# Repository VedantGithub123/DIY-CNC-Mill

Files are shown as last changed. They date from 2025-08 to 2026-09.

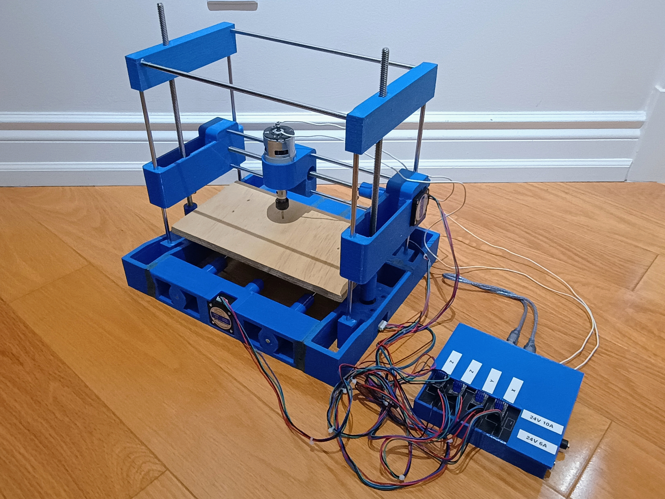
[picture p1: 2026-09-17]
media/build.jpg

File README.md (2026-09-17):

# Project Overview

The goal of this project is to develop a G-code interpreter and CNC mill. The CNC mill can follow straight lines, arcs and cubic bezier curves. It is 3D-printed with PETG, uses stepper motors, which are controlled with an Arduino Mega. The code ran on the laptop sends motor speeds to the Arduino, which moves the motors accordingly. To use the program, connect the Arudino Mega to your laptop with a USB cable. Run the Python file 

## Getting Started

SolidWorks is used for the CAD

KiCAD is used for the circuit diagram and PCB

Ensure Git is installed and setup to work with he repository

Clone the project repository to your local machine and navigate into the directory:
```
git clone https://github.com/VedantGithub123/DIY-CNC-Mill
cd DIY-CNC-Mill
```

Python and the PyGame library are needed

Arduino and the AccelStepper library are needed

## Repository Structure

The `main` branch is the organized working branch. Below is an overview of the folder structure for the `main` branch of this repository
```
DIY-CNC-Mill/
├── build/
├── electrical/
├── input/
├── media/
├── src/
│   ├── arduino/
│   ├── assets/
│   └── run.py
└── README.md
```

### Folder Descriptions

`build/`: Contains files relating to the physical construction of the device

&emsp;&emsp;`design/`: Contains the CAD files of the design

`electrical/`: Contains files relating to the electrical wiring of the device

`input/`: Location of G-code files to run

`media/`: Contains photos of the mill

`src/`: Contains all source code and assets

&emsp;&emsp;`arduino/`: Code to run on the Arduino

&emsp;&emsp;`assets/`: Photos needed for the GUI

&emsp;&emsp;`run.c`: Program to run on the laptop

`README.md`: Project repository documentation

## Program Design Process
Before deciding on how the program specifications were, I needed to determine how I wanted to organize the code. I wanted to keep the UI, G-code interpreter, and serial communication sections separate. A constant loop was needed for the UI, then when buttons are pressed, it would tell the CNC how to move or change the data, such as what file is being read. Finally, during the loop, the interpreter should calculate what speeds are needed and use the serial communication to send it to the Arduino.

### G-Code Protocol
I decided to follow this marlin G-code protocol (mostly): <https://marlinfw.org/meta/gcode/>

However, the only commands that can be used are:
- G0: Straight line max speed
- G1: Straight line controlled
- G2: Clockwise Arc
- G3: Counterclockwise Arc
- G4: Stop for time
- G5: Cubic Bezier Curve
- G9: Stop
- M0/M1/M2/M30: Stop the machine and spindle
- M3: Spindle on clockwise
- M4: Spindle on counterclockwise
- M5: Stop the spindle

### Speed Calculations
The path-following algorithms in `run.py` use the same control approach for straight lines, arcs, and cubic Bezier curves. Each path can provide a position and tangent for a given parameter, allowing the main update loop to follow different G-code commands without duplicating the motion-control logic.

During each update, the program determines the point on the active path that is closest to the current spindle position. It calculates the tangent at that point and combines it with a correction vector from the spindle to the path. The correction keeps the tool close to the programmed path, while the tangent continues the motion toward the end of the command. This produces the velocity vector that `run.py` sends to the Arduino through the serial connection.

The requested velocity is then constrained by the machine's acceleration and deceleration limits. At the beginning of a movement, the speed increases gradually. As the spindle approaches the endpoint, the speed is reduced so the target can be reached without overshooting. If the next movement is compatible with the current direction, the code can transition directly into it instead of stopping between commands; commands such as stops and dwells require the velocity to reach zero.

The update loop repeats these calculations while the machine is running. When the spindle is sufficiently close to the endpoint and its remaining velocity is small enough, `run.py` completes the current command and advances to the next one. This separates path geometry, speed limiting, and serial output while allowing the same motion loop to control lines, arcs, and Bezier curves.

### Serial Communication Protocol
When the computer tries to connect with the Arduino, the Arduino will say `CNC Ready`. The computer will need to read this before continuing. The Python program opens the Arduino's serial connection, waits for this ready message, and then begins sending movement and spindle commands generated by the G-code interpreter.

The Arduino program reads the commands received over the serial connection, converts them into motor and spindle actions, and uses the stepper-motor controllers to execute them. It continues processing incoming commands while the machine is running and reports status messages back to the computer when necessary. The Python program reads these responses so that it can keep the user interface and machine state synchronized.

If the ready message is not received, the Python program should not send movement commands. The Arduino must be connected over USB and powered before starting the Python program.

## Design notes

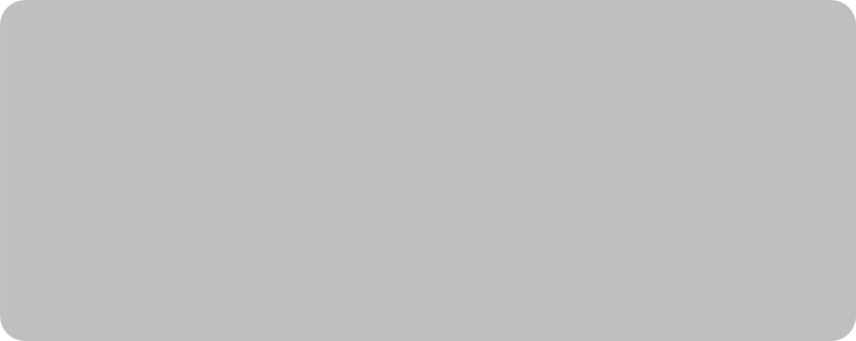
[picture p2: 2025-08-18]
src/assets/startHover.png

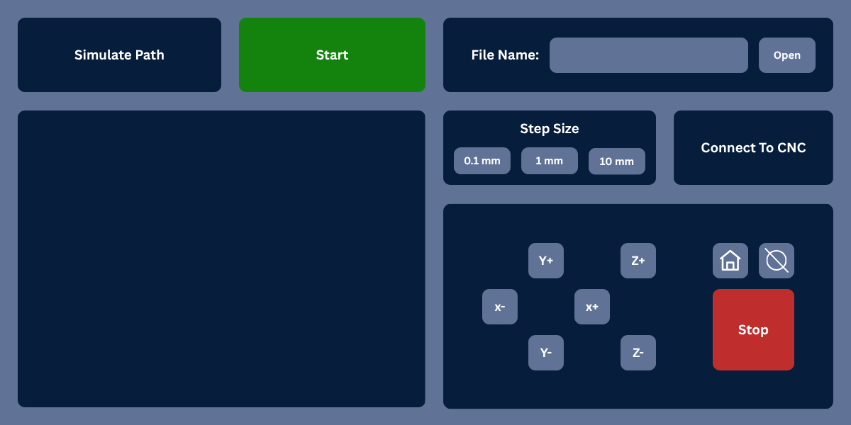
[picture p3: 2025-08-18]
media/software.png

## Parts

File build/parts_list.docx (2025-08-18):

# CNC DIY Materials List

Stepper Motors x4: https://www.amazon.ca/Stepper-63-74oz-42x39mm-Connector-Printer/dp/B07KZQ77VH/ref=sr_1_5

Stepper Drivers x1: https://www.amazon.ca/BIGTREETECH-TMC2209-Stepper-Driver-Printer/dp/B09YNFBGKJ/ref=sr_1_4_sspa

Lead Screws x2: https://www.amazon.ca/400mm%EF%BC%8815-75-Inches%EF%BC%89Tr8x8-Thread-Printer-Machine/dp/B08JPPC1TZ/ref=sr_1_5

Rails x5: https://www.amazon.ca/Linear-Motion-inches-Hardened-Printer/dp/B08JGD46P9/ref=sr_1_3_sspa

DC Motor x1: https://www.amazon.ca/Genmitsu-GS-775M-20000RPM-Spindle-Electrical/dp/B08DTHDSMV/ref=sr_1_1_sspa

DC Motor Driver x1: https://www.amazon.ca/DROK-Industrial-Controller-Optocoupler-Isolation/dp/B06XGD5SCB/ref=sr_1_7

Controller: https://www.amazon.ca/ELEGOO-Compatible-Arduino-Projects-Compliant/dp/B01H4ZDYCE/

Power Supply 24V 10A x1: https://www.amazon.ca/24V-10A-100-240V-Transformers-Universal/dp/B0D5HFD761/ref=sr_1_3

Power Supply 24V 6A x1: https://www.amazon.ca/Supply-Adapter-100-240V-Security-Upgrade/dp/B0BPLR1N6Y/ref=sr_1_6

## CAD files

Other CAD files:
build/design/assembly.SLDASM
build/design/Custom Parts/Base Brackets/Base_Corner_Bracket_Mirrored.SLDPRT
build/design/Custom Parts/Horizontal Brackets/Linear_Slide_Mount_Horizontal.SLDPRT
build/design/Custom Parts/Miscellaneous Parts/Electronics_Housing.SLDPRT
build/design/Custom Parts/Vertical Brackets/Vertical_Slide_Support.SLDPRT
build/design/Custom Parts/Base Brackets/Linear_Slide_Mount.SLDPRT
build/design/Custom Parts/Miscellaneous Parts/Spacer.SLDPRT
build/design/Custom Parts/Vertical Brackets/Linear_Slide_Mount_Vertical.SLDPRT
build/design/Imported Parts/300mm_Linear_Motion_Rod.SLDPRT
build/design/Custom Parts/Base Brackets/Base_Bracket_3.SLDPRT
build/design/Custom Parts/Vertical Brackets/Vertical_Slide_Support_Mirrorred.SLDPRT
build/design/Imported Parts/Nema17_Stepper_Motor.SLDPRT
build/design/Custom Parts/Base Brackets/Base_Bracket_1.SLDPRT
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

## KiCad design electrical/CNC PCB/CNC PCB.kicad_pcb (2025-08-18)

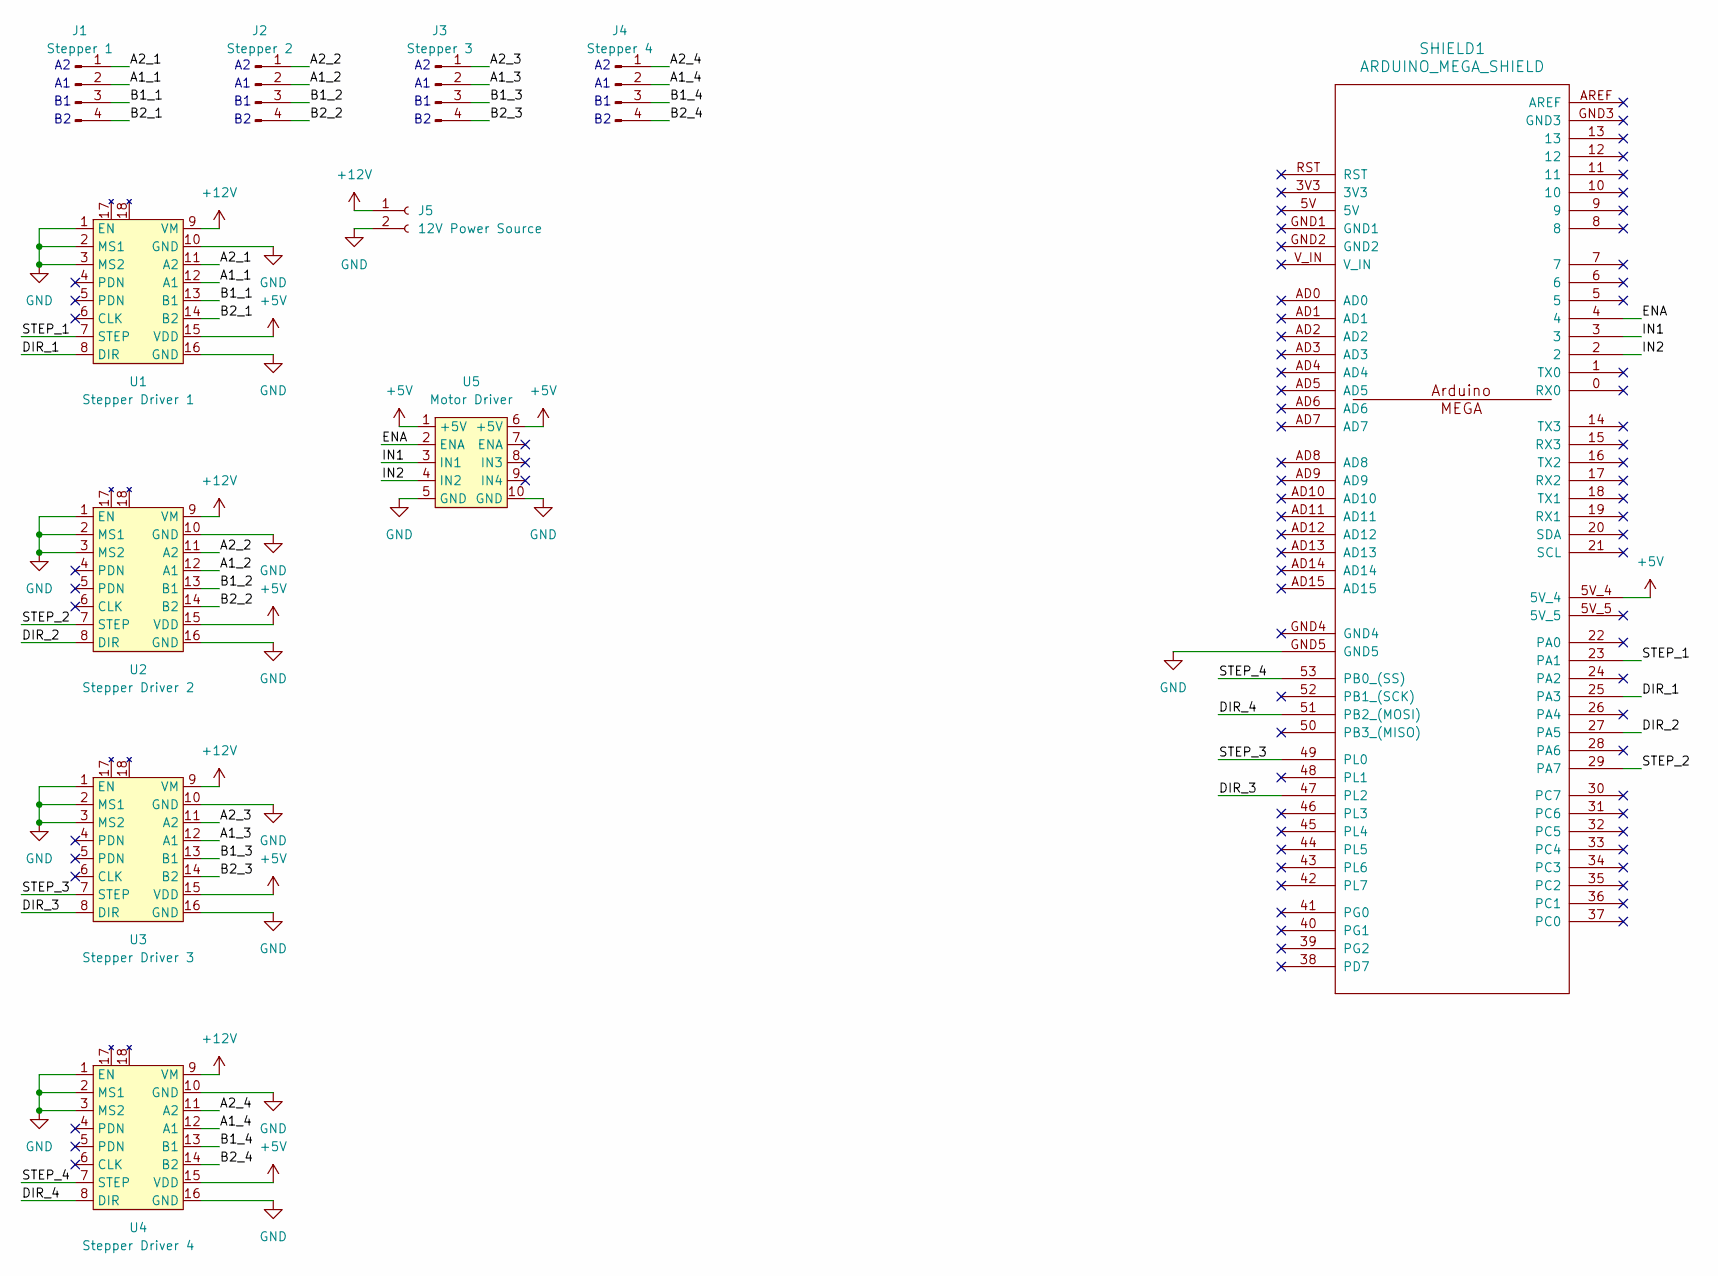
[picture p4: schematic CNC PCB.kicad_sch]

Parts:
J1: Stepper 1; 4 Pin Connector
J2: Stepper 2; 4 Pin Connector
J3: Stepper 3; 4 Pin Connector
J4: Stepper 4; 4 Pin Connector
J5: 12V Power Source; 2 Pin Connector
SHIELD1: ARDUINO_MEGA_SHIELD; ARDUINO MEGA SHIELD
U1: Stepper Driver 1; TMC2209
U2: Stepper Driver 2; TMC2209
U3: Stepper Driver 3; TMC2209
U4: Stepper Driver 4; TMC2209
U5: Motor Driver; L298

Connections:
+5V: SHIELD1.5V_4, U1.15 (VDD), U2.15 (VDD), U3.15 (VDD), U4.15 (VDD), U5.1 (+5V), U5.6 (+5V)
+12V: J5.1, U1.9 (VM), U2.9 (VM), U3.9 (VM), U4.9 (VM)
/A1_1: J1.2, U1.12 (A1)
/A1_2: J2.2, U2.12 (A1)
/A1_3: J3.2, U3.12 (A1)
/A1_4: J4.2, U4.12 (A1)
/A2_1: J1.1, U1.11 (A2)
/A2_2: J2.1, U2.11 (A2)
/A2_3: J3.1, U3.11 (A2)
/A2_4: J4.1, U4.11 (A2)
/B1_1: J1.3, U1.13 (B1)
/B1_2: J2.3, U2.13 (B1)
/B1_3: J3.3, U3.13 (B1)
/B1_4: J4.3, U4.13 (B1)
/B2_1: J1.4, U1.14 (B2)
/B2_2: J2.4, U2.14 (B2)
/B2_3: J3.4, U3.14 (B2)
/B2_4: J4.4, U4.14 (B2)
/DIR_1: SHIELD1.25 (PA3), U1.8 (DIR)
/DIR_2: SHIELD1.27 (PA5), U2.8 (DIR)
/DIR_3: SHIELD1.47 (PL2), U3.8 (DIR)
/DIR_4: SHIELD1.51 (PB2_(MOSI)), U4.8 (DIR)
/ENA: SHIELD1.4, U5.2 (ENA)
/IN1: SHIELD1.3, U5.3 (IN1)
/IN2: SHIELD1.2, U5.4 (IN2)
/STEP_1: SHIELD1.23 (PA1), U1.7 (STEP)
/STEP_2: SHIELD1.29 (PA7), U2.7 (STEP)
/STEP_3: SHIELD1.49 (PL0), U3.7 (STEP)
/STEP_4: SHIELD1.53 (PB0_(SS)), U4.7 (STEP)
GND: J5.2, SHIELD1.GND5, U1.1 (EN), U1.2 (MS1), U1.3 (MS2), U1.10 (GND), U1.16 (GND), U2.1 (EN), U2.2 (MS1), U2.3 (MS2), U2.10 (GND), U2.16 (GND), U3.1 (EN), U3.2 (MS1), U3.3 (MS2), U3.10 (GND), U3.16 (GND), U4.1 (EN), U4.2 (MS1), U4.3 (MS2), U4.10 (GND), U4.16 (GND), U5.5 (GND), U5.10 (GND)

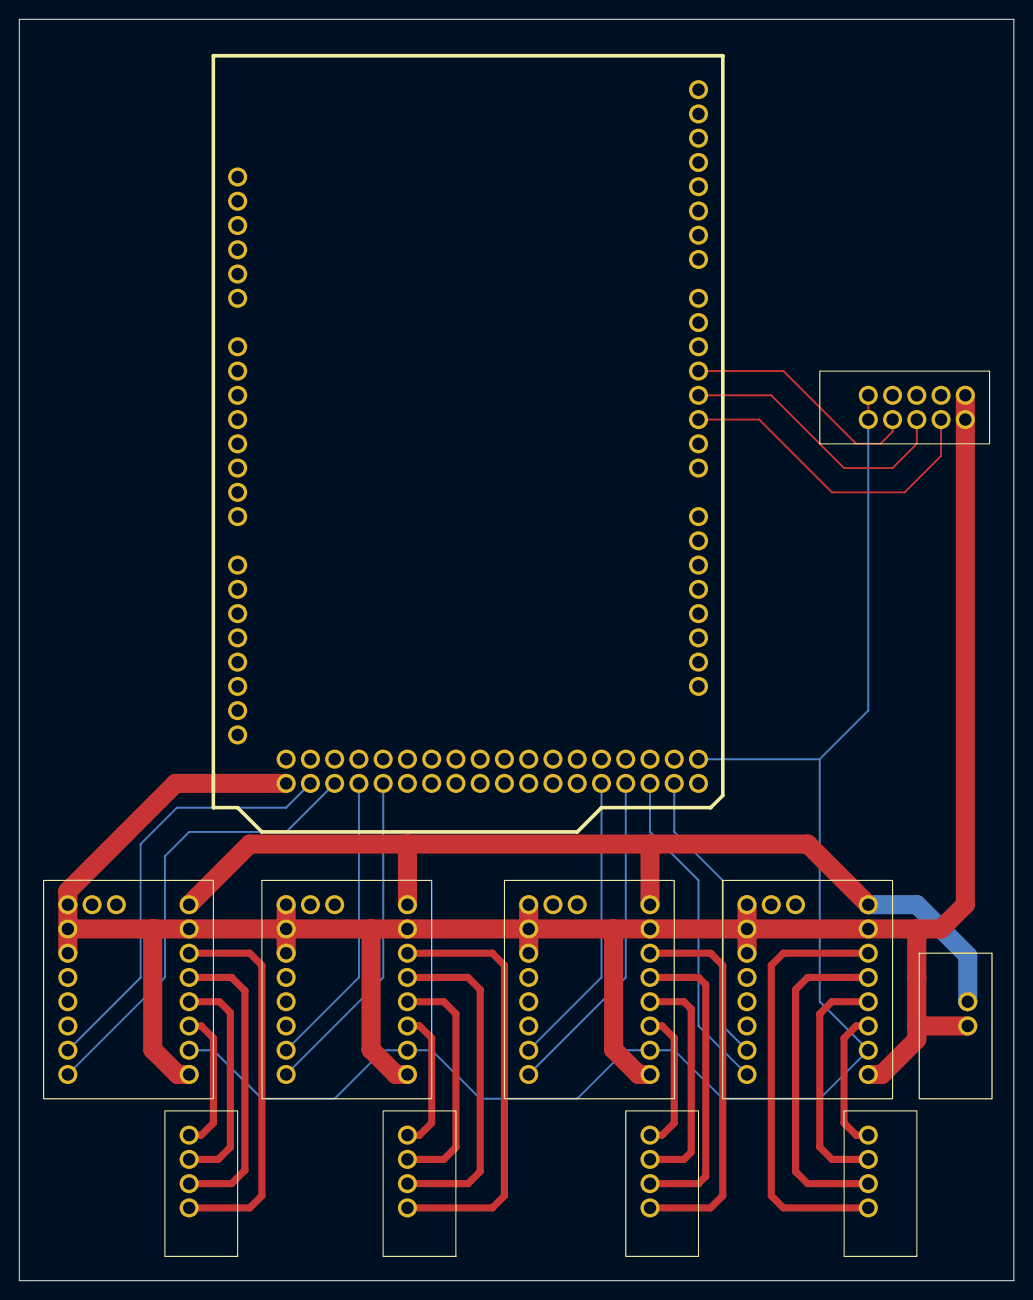
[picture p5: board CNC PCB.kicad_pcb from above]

Board: 2 copper layers, 104.1 x 132.1 mm, 11 parts (0 on the bottom side), 30 nets.

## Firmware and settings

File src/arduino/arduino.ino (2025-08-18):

#include <AccelStepper.h>
#define sgn(x) ((x) < 0 ? -1 : ((x) > 0 ? 1 : 0))

AccelStepper xStepper(AccelStepper::DRIVER, 23, 25);
AccelStepper yStepper(AccelStepper::DRIVER, 29, 27);
AccelStepper zStepper1(AccelStepper::DRIVER, 49, 47);
AccelStepper zStepper2(AccelStepper::DRIVER, 53, 51);

const int spindleEnable = 4;
const int spindleIn1 = 3;
const int spindleIn2 = 2;

int prevSpindleSpeed = 0;

int currentMessage = -1;
int targetBytes = 4;

float receivedFloat;
float myFloat = 1;
byte byteBuffer[4];

// Sets the spindle speed
void setSpindleSpeed(float speed)
{
  speed *= 255.0/100.0;
  for (int i = 0; i<=1000; i++)
  {
    digitalWrite(spindleIn1, map(i, 0, 1000, prevSpindleSpeed, speed) < 0);
    digitalWrite(spindleIn2, map(i, 0, 1000, prevSpindleSpeed, speed) > 0);
    analogWrite(spindleEnable, abs(map(i, 0, 1000, prevSpindleSpeed, speed)));
    delay(1);
  }
  prevSpindleSpeed = speed;
}

// Converts steps to mm
float stepsToMm(float steps)
{
  return steps/100.0;
}

// Converts mm to steps the stepper has to travel
long mmToSteps(float mm)
{
  return (long)(mm*100.0);
}

// Converts mm/min to steps/seconds
float mmMinToStepSeconds(float speed)
{
  return mmToSteps(speed)/60.0;
}

const long stepperMaxSpeed = mmMinToStepSeconds(1000);
const long stepperAccel = mmToSteps(3600000/3600);

void setup() {
  Serial.begin(1000000);
  Serial.setTimeout(1);

  pinMode(spindleIn1, OUTPUT);
  pinMode(spindleIn2, OUTPUT);
  pinMode(spindleEnable, OUTPUT);

  // Sets up steppers
  xStepper.setMaxSpeed(stepperMaxSpeed);
  yStepper.setMaxSpeed(stepperMaxSpeed);
  zStepper1.setMaxSpeed(stepperMaxSpeed);
  zStepper2.setMaxSpeed(stepperMaxSpeed);

  xStepper.setMinPulseWidth(0);
  yStepper.setMinPulseWidth(0);
  zStepper1.setMinPulseWidth(0);
  zStepper2.setMinPulseWidth(0);
  
  // Sets up stepper acceleration
  xStepper.setAcceleration(stepperAccel);
  yStepper.setAcceleration(stepperAccel);
  zStepper1.setAcceleration(stepperAccel);
  zStepper2.setAcceleration(stepperAccel);

  // Sets current position to 0
  xStepper.setCurrentPosition(0);
  yStepper.setCurrentPosition(0);
  zStepper1.setCurrentPosition(0);
  zStepper2.setCurrentPosition(0);

  // Tells computer that it is ready
  Serial.println("CNC Ready");
}

void loop() {
  // Checks if serial monitor is available
  if (Serial.available() >= targetBytes)
  {
    if (currentMessage == -1)
    {
      // Read first 4 and change current message and target bytes
      for (int i = 0; i < 4; i++) {
        byteBuffer[i] = Serial.read();
      }
      memcpy(&receivedFloat, byteBuffer, sizeof(receivedFloat));
      currentMessage = (int) receivedFloat;

      if (currentMessage == 0)
      {
        xStepper.setCurrentPosition(0);
        yStepper.setCurrentPosition(0);
        zStepper1.setCurrentPosition(0);
        zStepper2.setCurrentPosition(0);
        myFloat = 1;
        Serial.write((uint8_t*)&myFloat, sizeof(myFloat));
        currentMessage = -1;
      }
      else if (currentMessage == 1)
      {
        myFloat = stepsToMm(xStepper.currentPosition());
        Serial.write((uint8_t*)&myFloat, sizeof(myFloat));
        myFloat = stepsToMm(yStepper.currentPosition());
        Serial.write((uint8_t*)&myFloat, sizeof(myFloat));
        myFloat = stepsToMm(zStepper1.currentPosition());
        Serial.write((uint8_t*)&myFloat, sizeof(myFloat));
        currentMessage = -1;
      }
      else if (currentMessage == 2)
      {
        targetBytes = 4;
      }
      else if (currentMessage == 3)
      {
        targetBytes = 4;
      }
      else if (currentMessage == 4)
      {
        targetBytes = 4;
      }
      else if (currentMessage == 5)
      {
        targetBytes = 4;
      }
      else if (currentMessage == 6)
      {
        targetBytes = 12;
      }
    }
    else
    {
      if (currentMessage == 2)
      {
        for (int i = 0; i < 4; i++) {
          byteBuffer[i] = Serial.read();
        }
        memcpy(&receivedFloat, byteBuffer, sizeof(receivedFloat));
        setSpindleSpeed(receivedFloat);
        myFloat = 1;
        Serial.write((uint8_t*)&myFloat, sizeof(myFloat));

        currentMessage = -1;
        targetBytes = 4;
      }
      else if (currentMessage == 3)
      {
        for (int i = 0; i < 4; i++) {
          byteBuffer[i] = Serial.read();
        }
        memcpy(&receivedFloat, byteBuffer, sizeof(receivedFloat));
        yStepper.setMaxSpeed(stepperMaxSpeed);
        yStepper.runToNewPosition(yStepper.currentPosition()+mmToSteps(receivedFloat));
        myFloat = 1;
        Serial.write((uint8_t*)&myFloat, sizeof(myFloat));

        currentMessage = -1;
        targetBytes = 4;
      }
      else if (currentMessage == 4)
      {
        for (int i = 0; i < 4; i++) {
          byteBuffer[i] = Serial.read();
        }
        memcpy(&receivedFloat, byteBuffer, sizeof(receivedFloat));
        zStepper1.setMaxSpeed(stepperMaxSpeed);
        zStepper2.setMaxSpeed(stepperMaxSpeed);
        zStepper1.move(mmToSteps(receivedFloat));
        zStepper2.move(mmToSteps(receivedFloat));
        while (abs(zStepper1.distanceToGo()) > 0 || abs(zStepper2.distanceToGo()) > 0)
        {
          zStepper1.run();
          zStepper2.run();
        }
        zStepper1.setSpeed(0);
        zStepper2.setSpeed(0);
        myFloat = 1;
        Serial.write((uint8_t*)&myFloat, sizeof(myFloat));

        currentMessage = -1;
        targetBytes = 4;
      }
      else if (currentMessage == 5)
      {
        for (int i = 0; i < 4; i++) {
          byteBuffer[i] = Serial.read();
        }
        memcpy(&receivedFloat, byteBuffer, sizeof(receivedFloat));
        xStepper.setMaxSpeed(stepperMaxSpeed);
        xStepper.runToNewPosition(xStepper.currentPosition()+mmToSteps(receivedFloat));
        myFloat = 1;
        Serial.write((uint8_t*)&myFloat, sizeof(myFloat));

        currentMessage = -1;
        targetBytes = 4;
      }
      else if (currentMessage == 6)
      {
        for (int i = 0; i < 4; i++) {
          byteBuffer[i] = Serial.read();
        }
        memcpy(&receivedFloat, byteBuffer, sizeof(receivedFloat));
        xStepper.setSpeed(mmMinToStepSeconds(receivedFloat));

        for (int i = 0; i < 4; i++) {
          byteBuffer[i] = Serial.read();
        }
        memcpy(&receivedFloat, byteBuffer, sizeof(receivedFloat));
        yStepper.setSpeed(mmMinToStepSeconds(receivedFloat));

        for (int i = 0; i < 4; i++) {
          byteBuffer[i] = Serial.read();
        }
        memcpy(&receivedFloat, byteBuffer, sizeof(receivedFloat));
        zStepper1.setSpeed(mmMinToStepSeconds(receivedFloat));
        zStepper2.setSpeed(mmMinToStepSeconds(receivedFloat));

        myFloat = 1;
        Serial.write((uint8_t*)&myFloat, sizeof(myFloat));

        currentMessage = -1;
        targetBytes = 4;
      }
    }
  }

  xStepper.runSpeed();
  yStepper.runSpeed();
  zStepper1.runSpeed();
  zStepper2.runSpeed();
}

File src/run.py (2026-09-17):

import pygame_widgets
import pygame
from pygame_widgets.textbox import TextBox
import time
import numpy as np
import math
import sys, threading, queue, serial
import serial.tools.list_ports
import struct
from pathlib import Path

# Arduino Class (Used for interfacing)
class Arduino:
    # Defines class attributes
    def __init__(self):
        self.connectedPort = ""
        self.portOptions = []
        self.connectedDevice = None
        self.isConnected = False
    
    # Connects to selected port (0: Unable to connect 1: Connected successfully)
    def connect(self, baudRate = 1000000, timeout = 10):
        self.isConnected = False

        # Finds the correct port
        port = serial.tools.list_ports.comports()
        self.connectedPort = port[0]
        for i in list(port):
            if "Arduino Mega 2560" in i.description:
                self.connectedPort = i
        self.connectedDevice = self.connectedPort.device
        self.connectedDevice = serial.Serial(self.connectedDevice, baudrate=baudRate, timeout=.1)

        # Checks to see if the device is correct
        message = b''
        refTime = time.time()
        while time.time()-refTime < timeout:
            incoming = self.connectedDevice.read()
            if incoming == b'\n':
                try:
                    message = message.decode('utf-8').strip()
                    if message == "CNC Ready":
                        self.isConnected = True
                        return 1
                    else:
                        return 0
                except:
                    return 0
            else:
                if incoming not in (b'', b'\r'):
                    message += incoming
        return 0

    # Writes message to arduino
    def write(self, message):
        if self.isConnected:
            self.connectedDevice.write(struct.pack('f', message))

    # Read message from arduino
    def read(self, timeout = 1):
        if self.isConnected:
            message = b''
            refTime = time.time()
            while time.time()-refTime < timeout:
                incoming = self.connectedDevice.read()
                if len(incoming) >= 1:
                    message += incoming
                if len(message) == 4:
                    try:
                        return struct.unpack('f', message)[0]
                    except:
                        raise Exception("Invalid message")
            raise Exception("Timeout")
        raise Exception("Not Connected")

# CNC Class (All units in mm)
class CNC:
    def __init__(self, minSpeed, maxSpeed, startingFeedRate, maxAcceleration, spindleMaxSpeed, pathAttraction, tolerance, divisions):
        # Variables to store speed
        self.velocity = np.array([0.0, 0.0, 0.0])

        # Variables to store position
        self.position = np.array([0.0, 0.0, 0.0])

        # Variables to store current target
        self.target = np.array([0.0, 0.0, 0.0])

        # Variables to store previous target point
        self.prevTarget = np.array([0.0, 0.0, 0.0])
        self.prevTarget2 = np.array([0.0, 0.0, 0.0])

        # Variable to store the path as a list of strings
        self.path = [""]

        # Variable to store which step the cnc is on
        self.step = 0

        # Variable to store the last update time
        self.lastUpdateTime = -1

        # Variable to store speed and accelerations
        self.minSpeed = minSpeed
        self.maxSpeed = maxSpeed
        self.startingFeedRate = startingFeedRate
        self.feedRate = self.startingFeedRate
        self.maxAcceleration = maxAcceleration

        # Variables to store the spindle speeds
        self.spindleMaxSpeed = spindleMaxSpeed

        # Variable to store tuning parameter
        self.pathAttraction = pathAttraction

        # Variable to store tolerance
        self.tolerance = tolerance

        # Variable to store number of divisions of a path
        self.divisions = divisions

        # Variable to store the feed rate of the last step
        self.prevFeedRate = self.feedRate

        self.arduino = Arduino()

        self.simulate = True

    # Connects to the arduino
    def connect(self):
        return self.arduino.connect()

    # Checks if arduino is connected
    def isConnected(self):
        return self.arduino.isConnected
    
    # Sets whether or not the machine will simulate or not
    def setSimulation(self, state):
        self.simulate = state

    # Sets the velocity of the toolhead
    def setVelocity(self, newVelocity):
        self.velocity = np.copy(newVelocity)
        if (not self.simulate):
            self.arduino.write(6)
            self.arduino.write(newVelocity[0])
            self.arduino.write(newVelocity[1])
            self.arduino.write(newVelocity[2])
            self.arduino.read()

    # Zeroes the position of the toolhead
    def resetPosition(self):
        self.position = np.array([0.0, 0.0, 0.0])
        if (not self.simulate):
            self.arduino.write(0)
            self.arduino.read()
    
    # Gets the velocity of the toolhead
    def getVelocity(self):
        return np.copy(self.velocity)

    # Gets the position of the toolhead
    def getPosition(self):
        return np.copy(self.position)
    
    # Writes a message to the cnc
    def writeCNC(self, command):
        if (not self.simulate):
            self.arduino.write(command)
    
    def readCNC(self, t=5):
        if (not self.simulate):
            self.arduino.read(timeout=t)

    # Updates the position of the toolhead
    def updatePosition(self):
        if (not self.simulate):
            self.arduino.write(1)
            self.position = np.array([self.arduino.read(), self.arduino.read(), self.arduino.read()])
        else:
            timeElapsed = ((time.time_ns()-self.lastUpdateTime)/(10**9))/60
            self.lastUpdateTime = time.time_ns()
            self.position += timeElapsed*self.velocity

    # Sets the speed of the spindle
    def setSpindleSpeed(self, speed):
        if (not self.simulate):
            self.arduino.write(2)
            self.arduino.write(speed)
            self.arduino.read(timeout=2)
    
    # Sets the path of the toolhead
    def setPath(self, p):
        self.path = p.split("\n")

        # Variables to store speed
        self.velocity = np.array([0.0, 0.0, 0.0])

        # Variables to store position
        self.position = np.array([0.0, 0.0, 0.0])

        # Variables to store current target
        self.target = np.array([0.0, 0.0, 0.0])

        # Variables to store previous target point
        self.prevTarget = np.array([0.0, 0.0, 0.0])
        self.prevTarget2 = np.array([0.0, 0.0, 0.0])

        # Variable to store which step the cnc is on
        self.step = 0

        # Variable to store the last update time
        self.lastUpdateTime = -1
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

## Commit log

2025-08-22 Changed CAD Model
    [Electronics_Housing.SLDPRT, Full_Assembly.SLDASM, Linear_Slide_Mount.SLDPRT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]
2026-09-17 Organize repository
    [300mm_Lead_Screw.SLDPRT, 300mm_Linear_Motion_Rod.SLDPRT, Base_Bracket_1.SLDPRT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]
